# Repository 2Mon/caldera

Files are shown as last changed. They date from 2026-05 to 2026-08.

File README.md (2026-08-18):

<p align="center">
  
</p>

# Caldera
A high performance, lightweight, CNC machined hotend designed for high speed printing

Caldera is built around a 110w Supervolcano heater with a CNC Copper heat block. The goal of this hotend is to maximize melt zone while keeping weight to a minimum.

# Specs
* 51mm Melt Zone
* PT1000 Filament Sensor
* 110w Supervolcano Heater 
* Conduction or Air Cooled
* M3 Mount Pattern

## BOM
Found in Caldera_BOM.csv

# Acknowledgements

Huge thanks to these awesome people for giving me advice and feedback on my design

* @bagelthedev
* @tortlegod
* @burgo_enemy_of_thelettuce

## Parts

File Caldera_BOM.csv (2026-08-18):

Item | Quantity | Price | Total Cost | Link
CNC/SLM Parts | 1 | 100 | 100 | JLC CNC
Supervolcano Heater | 1 | 22 | 22 | https://www.lukeslabonline.com/products/high-wattage-heater?variant=47315067339053
PT1000 | 1 | 12 | 12 | https://www.lukeslabonline.com/products/pt1000-rtd-sensor-e3d-dragonfly-dragon-mosquito-compatible
M2 Grub Screw | 1 | 6 | 6 | https://www.amazon.com/uxcell-Repairing-Instruments-Machinery-Equipment/dp/B0DDJBSF6B
v6 smooth heatbreak | 1 | 7 | 7 | https://www.aliexpress.us/item/3256803255102947.html?
boron nitride paste | 1 | 13 | 13 | https://lettucehead3d.com/product/boron-nitride-paste/
 |  |  | 0
 |  |  | 0
 |  |  | 0
 |  |  | 0

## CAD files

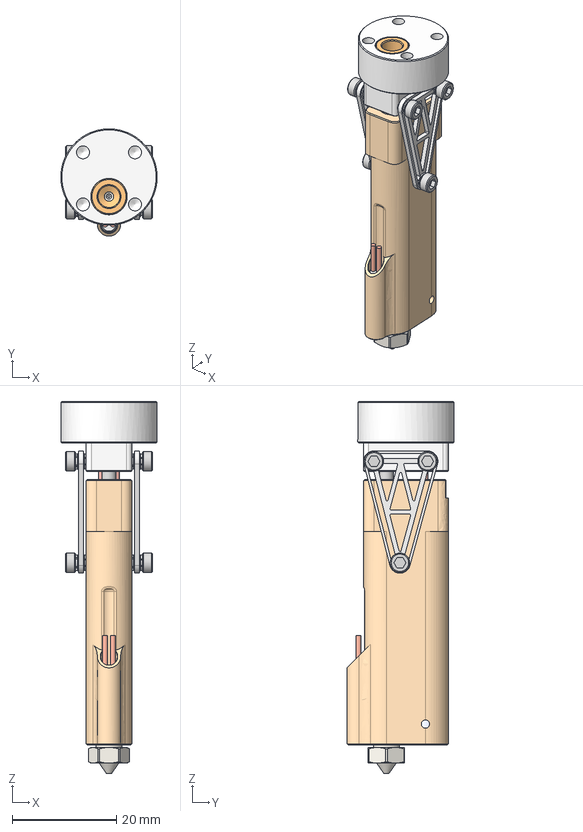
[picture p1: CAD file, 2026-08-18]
Caldera.step
18.5 x 20.6 x 71.5 mm
E3D v6 HotEnd - Nozzle

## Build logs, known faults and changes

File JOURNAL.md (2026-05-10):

---
title: "Caldera"
author: "1Mon"
description: "supervolcano heater hotend with 51mm of meltzone"
created_at: "2026-05-8"
---

# Research | 5/6/26

Hotend design!! this is my second shot at making a decent hotend. My goals for this are to have a large melt zone, nice heater, filament path, and thermistor packaging, while keeping it small and lightweight. I was inspired by hotends like v9 (https://www.v9hotend.com/), tricorn (http://tricornhotend.com/) and Turtle's double barrel hotend he made for #rework (https://github.com/ProgrammerTurtle/DoubleBarrel). These all have CNC'd heater blocks and heatsinks. 

My idea for this hotend is to use a supervolcano heater cartridge (likely a high wattage one from Lukes Lab), in combonation with a very light weight and compact block to have as little temperature gradient between the heater and the thermistor as possible. 

You can see that idea here in Turtle's hotend. 



The heaters are extremely close to the filament path and nozzle, which means that they dont waste energy heating the rest of the block. The walls are also very thin, which means that less heat is lost into the block. Another advantage of this is that the thermistor is able to read a very accurate temperature at the nozzle. The further the thermistor is from the heater the larger the difference will be.

**Total time spent: 3 hours**

# Block Design | 5/6/26

There are multiple things I needed to balance in the block design for this hotend.
1. Performance: this is pretty self explanitory. I want big meltzone so lots of plastic can be pushed out. 
2. Manufacturability (is that a word?): Even though I am not the one who is milling this part, I dont want the JLCCNC worker machining this to have a hard time. Also other people might want to machine it themselves. 
3. Cost: Keep the machining simple so cost is low
4. Weight: I had to keep all the parts as light as possible. This is going to be moving at high speeds, so the less weight the better the rigidity will be. Low rigidity leads to crap print quality. 

The design is fairly simple. I started with a couple circles to give holes for the heater bore, meltzone, and thermisor to sit. I origonally planned to use an M3 pt1000 thermistor, but was told that a cartridge thermistor would have better thermal control. 


I basically just extruded that upwards enough to fit the threaded part of a heatbreak, a supervolcano nozzle adapter (more on that in a sec), and a nozzle. I also added a section at the top for heatbreak stuff. 



I added features to allow the pt1000 and heater to fit in, and cleaned up the cad a bit. 



Here you can see something close to the final heater block design. I added holes for grubscrews to clamp the heater as well as mounting holes for the heatsink mounts. 

About the supervolcano adapter. JLC does not like drilling 2mm holes 51mm long. So instead ill be using an m6 tap all the way through the part to create a 2mm hole. nice! and its cheap too. This also gives me a really nice mating surface for the nozzle so overall really helpful.

**Total time spent: 6 hours**

# Heatsink Design | 5/7/26

I started this project thinking that I would make the hotend air cooled. I realized pretty quickly that that wouldnt work very well for a number of reasons. If the filament path was centered in the heatsink, then there wouldnt be much of an issue with turning a decent heatsink. But since the filament path is not centered, turning it would be literally impossible. You can see here how difficult it would be to turn that. 



I ended up switching to a new idea. Conduction! why have heatsink fins when you can have a big block of metal for a toolhead. ok very cool! 



You can see the big block here ^^

The way the heatsink is mounted is pretty interesting IMO. I am using two SLM Titanium arms to connect the heatsink to the block. Since titanium has fairly low heat conductivity, its pretty perfect for this. The geometry also helps a lot with stopping excess heat from going into the block. You can see how everything connects together with m2 screws here. 



I designed in some interesting geometry on the connector itself to try to minimise contact area between the block and the connector. it kinda looks like a castle.  



Im using a standard v6 heatbreak in this hotend. It has a smooth side and a threaded side, which lets me use my fancy mounting style accurately. yay! 

**Total time spent: 4 hours**

# Polish | 5/8/26

I spent this session polishing the design. This includes assembling everything in cad, thinking about a real life assembly process, and making a couple renders of the project. 

Here you can see how the entire design comes together. The filament path is like this: Heatbreak -> Supervolcano adapter -> Nozzle. Overall really simple. You can also see how close together everything else is in this view, which includes the heater, thermistor, and filament path. You can also see how efficient the heatbreak mounting is. yay!



**Total time spent: 2 hours**

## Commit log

2026-05-08 Update JOURNAL.md with hotend design details
    Document the design and considerations for a new hotend.
2026-05-08 Change total time spent from 3 to 6 hours
    Updated the total time spent on the heater block design.
2026-05-08 Update JOURNAL.md with heatsink design details
    Added detailed notes on heatsink design and modifications, including images and time spent.
2026-05-08 Enhance README with Caldera hotend details
    Added detailed description and specifications for the Caldera hotend.
2026-05-09 Update JOURNAL.md with polishing session details
    Documented the design polishing session and assembly process.
2026-05-10 Revise heatsink design entry title format
    Updated the title format of the heatsink design entry for clarity.
2026-08-18 add bom
    [Caldera_BOM.csv]
2026-08-18 add step
    [Caldera.step]
2026-08-18 Revise hotend description for high speed printing
    Updated description for clarity on printing speeds.
2026-08-18 Update BOM file reference in README
2026-08-18 Fix heading formatting for BOM section
